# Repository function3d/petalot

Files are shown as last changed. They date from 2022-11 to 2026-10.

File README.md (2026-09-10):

# Petalot

## From PET Bottle To 3D Filament

Petalot

 - [Buy it ready-made](https://function3d.xyz/shop/)
 - [FAQs](https://function3d.xyz/faqs)
 - [How to build it](https://www.tiktok.com/@function.3d/playlist/PETALOT%20Build-7340398832935521056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)
 - [STLs](https://makerworld.com/en/models/190886-petalot-plastic-bottles-into-3d-filament)

## Bill of material
 - [BOM](https://function3d.xyz/bom/)

## Electronics

Petalot

 - [Buy it ready-made](https://function3d.xyz/shop/)
 - **UPDATE**: the firmware you need depends on your PCB version — v1.4.5 (DIY) and v1.5.1/v1.5.2 (commercial). See the [Firmware README](Firmware/README.md).
 - [Gerber](https://github.com/function3d/petalot/raw/master/Schematic/Gerber_v1.1_2023-01-02.zip) for PCB fabrication, just upload this zip file to [jlcpcb.com](https://jlcpcb.com/?from=FUNC) and order your PCB.
 - [Schematic](https://github.com/function3d/petalot/tree/master/Schematic)
 - [Firmware](https://github.com/function3d/petalot/tree/master/Firmware)
 - [Before switching on the electronics for the first time](https://github.com/function3d/petalot/blob/5b1d409dda7f66e7040381943212c45b0bf8b62b/before%20you%20switching%20on%20the%20electronics.md)
	 
## Bottle cutter
Bottle cutter

 - [Buy it ready-made](https://function3d.xyz/shop/)
 - [STLs](https://makerworld.com/en/models/190890-bottle-cutter-variable-cutting-guide-no-blades)
 - [How to build it](https://youtu.be/hEdDhRgakms)

## Social
  Follow me on [Youtube](https://www.youtube.com/channel/UC4UBuZ5YRTo5XYFUxdkmqkg), [Tiktok](https://www.tiktok.com/@function.3d) and [Instagram](https://www.instagram.com/function.3d/) for more tutorials and information.

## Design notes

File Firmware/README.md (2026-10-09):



# PETALOT Firmware

There is **one firmware**, built separately for each PCB version. The three
builds are functionally identical and share the same web UI; they only differ
in the microcontroller pin mapping (defined in `pins.hpp`). Pick the `.bin`
that matches the PCB you have installed.

## Which firmware do I need?

| PCB version | Firmware file | Availability |
| --- | --- | --- |
| **v1.4.5** | [`petalot.1.4.5-v1.6.4.bin`](petalot/build/esp8266.esp8266.d1_mini_clone/petalot.1.4.5-v1.6.4.bin) | **DIY** — the only board released publicly. |
| **v1.5.1** | [`petalot.1.5.1-v1.6.4.bin`](petalot/build/esp8266.esp8266.d1_mini_clone/petalot.1.5.1-v1.6.4.bin) | **Commercial**. |
| **v1.5.2** | [`petalot.1.5.2-v1.6.4.bin`](petalot/build/esp8266.esp8266.d1_mini_clone/petalot.1.5.2-v1.6.4.bin) | **Commercial** (current). |

- If you built your own PETALOT from the public files, your PCB is the **v1.4.5**.
- Versions **v1.5.1** and **v1.5.2** are only fitted on commercially sold machines.

> Do not flash a firmware that does not match your PCB.

## Identify your PCB

| v1.4.5 (DIY) | v1.5.1 | v1.5.2 |
| --- | --- | --- |
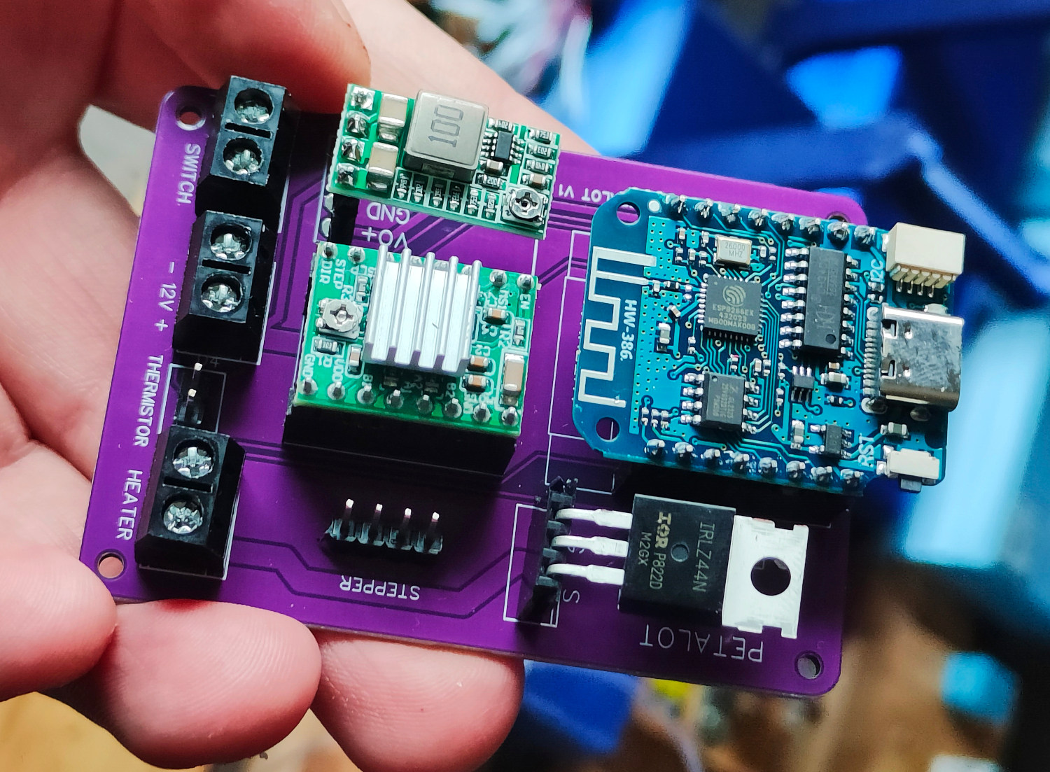
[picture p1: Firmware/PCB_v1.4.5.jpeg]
PCB v1.4.5
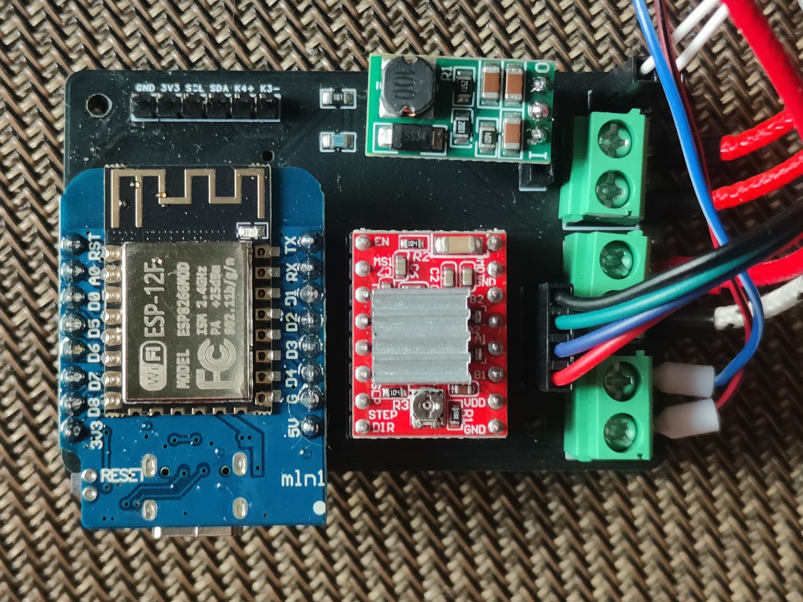
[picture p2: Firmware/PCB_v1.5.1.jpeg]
PCB v1.5.1
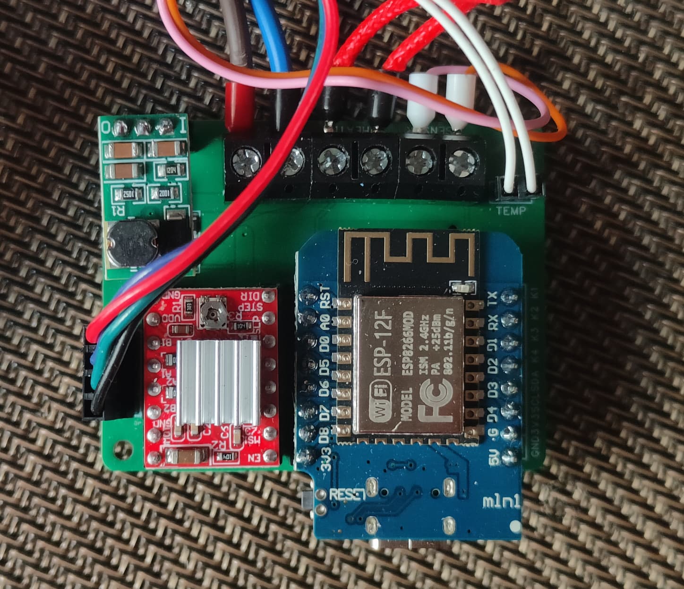
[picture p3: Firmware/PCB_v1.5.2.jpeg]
PCB v1.5.2
|  |  |  |

## First-time flash

1. Connect the Wemos to your PC.
2. Go to https://web.esphome.io/
3. Click **Connect**, select **USB Serial** port and **Connect**.
4. Click **Install**, then **Choose File**, select the `.bin` for your PCB and click **Install**.
5. Connect your phone to the Wi-Fi "PETALOT-XXXXXX" and browse to 192.168.4.1.
6. (Optional) Enter your local Wi-Fi SSID, password, IP address and subnet.

## Updating an existing device

You do not need a cable: update over the air.

### Online update (one-click, needs Internet while you do it)

Open the web UI and go to **Settings → Advanced → Online update**, then click
**Check for updates**. If a newer firmware for your PCB is available, click
**Install update** and it updates by itself.

This works when the device is connected to your home Wi-Fi: your computer or
phone is then on the same network, so it has Internet access and can fetch and
send the update. **It does not work while you are connected directly to the
device's own Wi-Fi hotspot** ("PETALOT-XXXXXX"): while connected to that, your
computer or phone has no Internet, so it cannot check or download anything. In
that case use the manual update below — it works with no Internet at all.

### Manual update (works offline, no Internet needed)

Use this if the device is not on your home Wi-Fi (for example, right out of the
box, when you connect directly to its "PETALOT-XXXXXX" network).

1. Download the `.bin` for your PCB from this repository
   (`petalot.1.4.5-v1.6.4.bin`, `petalot.1.5.1-v1.6.4.bin` or
   `petalot.1.5.2-v1.6.4.bin`).
2. Open the web UI and go to **Settings → Advanced → Firmware Update**, pick the
   file and click **Update**. (Or browse to `http://<device-ip>/update` — the
   built-in update page available on **every** firmware version.)

## Building from source

1. Open `Firmware/petalot/petalot.ino` in the Arduino IDE.
2. Set `PCB` to the hardware you are compiling for:

   | `PCB` | Hardware |
   | --- | --- |
   | `1405` | v1.4.5 |
   | `1501` | v1.5.1 |
   | `1502` | v1.5.2 |

3. Set `VERSION` to the firmware version you are publishing (e.g. `1600`).
   `VERSION` is independent of the PCB revision and is what the online update
   compares against `latest.json`.
4. Select **Tools > Board > esp8266 > LOLIN(WEMOS) D1 mini (clone)**.
5. Compile and upload.

The pin mapping for every hardware revision lives in `Firmware/petalot/pins.hpp`.
See [`INSTALL_LIBRARIES.md`](petalot/INSTALL_LIBRARIES.md) for the
required libraries and board setup.

### Previewing the web UI without flashing

[`tools/webui_preview.py`](tools/webui_preview.py) serves `web_ui.h` in your
browser (mock data, or proxied to a real device) so you can edit the UI and
press F5 — no build or flash. See [`tools/README.md`](tools/README.md).

### Publishing an online update

1. Build the three firmwares (one per `PCB`) with the new `VERSION`.
2. Regenerate the manifest:

   ```
   python3 Firmware/tools/gen_latest_json.py <VERSION>
   ```

   This writes `latest.json` next to the `.bin` files, with the version, file
   name and size for every PCB.
3. Commit and push the three `.bin` files and `latest.json` to the repository
   (the online update reads them from `master`).

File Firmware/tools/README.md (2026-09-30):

# Firmware tools

Helper scripts used to build, publish and preview the PETALOT firmware.
All are plain Python 3 / Bash with no third-party packages.

## webui_preview.py — preview the web UI without flashing

The whole UI is a single C raw string inside `petalot/web_ui.h`. This script
extracts it and serves it over HTTP, answering the device API (`/get`, `/tele`,
`/set`, `/reset`, `/updatecheck`, `/update`) so you can open the UI in a
browser and iterate on it. `web_ui.h` is re-read on every page request, so
editing it and pressing **F5** is enough — no build, no flash.

```bash
Firmware/tools/webui_preview.py                        # mock, http://0.0.0.0:8080
Firmware/tools/webui_preview.py --device http://192.168.4.1   # proxy to a device
Firmware/tools/webui_preview.py --port 9000 --open
```

Two modes:

- **Mock** (default): answers the API with synthetic data (a slowly warming
  temperature, moving counters, editable settings). Good for layout, i18n and
  styling work with no hardware at all.
- **Proxy** (`--device URL`): serves the local HTML but forwards the API to a
  real device, so you preview your UI changes against live data. Use the device
  AP address (`http://192.168.4.1`) or its LAN IP.

Options:

| Option | Meaning |
| --- | --- |
| `--host` | bind address (default `0.0.0.0`, reachable from your phone) |
| `--port` | port (default `8080`) |
| `--device URL` | proxy the device API to this URL instead of mock data |
| `--open` | open the preview in the default browser |

Note: the online update check downloads `latest.json` and the `.bin` from
GitHub **in your browser**, so that part works in the preview too.

## check_web_ui.py — static UI checks

The UI lives in one big string; a stray apostrophe or unbalanced brace breaks
it silently. This checker catches that plus i18n key mismatches. `release.sh`
runs it before every build.

```bash
python3 Firmware/tools/check_web_ui.py [Firmware/petalot/web_ui.h]
```

The checker also warns when `web_ui_gz.h` is older than `web_ui.h` (i.e. the
gzip-packed UI on device is stale).

## gen_web_gzip.py — pack the UI into a gzip PROGMEM blob

The web UI is ~100 KB of HTML/CSS/JS. Serving it compressed makes page loads
much faster on the ESP's slow WiFi. This script gzip-compresses the `INDEX_HTML`
raw string from `web_ui.h` and writes `web_ui_gz.h` (bytes + length + ETag),
which `server.hpp` serves with `Content-Encoding: gzip`.

```bash
python3 Firmware/tools/gen_web_gzip.py          # web_ui.h -> web_ui_gz.h
python3 Firmware/tools/gen_web_gzip.py --input path/web_ui.h --output path/web_ui_gz.h
```

Run it after **every** edit to `web_ui.h`, or `release.sh` will do it for you.
The gzip is deterministic (mtime=0) so the ETag is stable across identical
inputs.

## gen_latest_json.py — regenerate the update manifest

Writes `latest.json` (the file the browser reads for the online update) with
the version, file name and size of each PCB build.

```bash
python3 Firmware/tools/gen_latest_json.py <VERSION>
```

## release.sh — build and publish a release

Builds the three PCB flavours (1405 / 1501 / 1502), writes the versioned
binaries `petalot.<hw>-v<fw>.bin`, deletes the previous versioned builds,
regenerates `latest.json` and updates the file names in `Firmware/README.md`.

```bash
Firmware/tools/release.sh          # build with the VERSION already in petalot.ino
Firmware/tools/release.sh 1601     # set VERSION 1601 (= 1.6.1) and build

git add Firmware/petalot/petalot.ino Firmware/petalot/build/esp8266.esp8266.d1_mini_clone/ Firmware/README.md
git commit -m "firmware: v1.6.1"
git push
```

Environment overrides: `ARDUINO_CLI`, `ARDUINO_CLI_CONFIG`, `FQBN`.

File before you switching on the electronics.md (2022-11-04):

# Before switching on the electronics for the first time
## Set to 5V output on D3 DC-DC step down
### Option 1
- You put 12v between IN and GND
- With a multimeter you measure VO and GND
- Turn the potentiometer until you measure 5V
### Option 2
- Cut the jumper on ADJ
- Put a drop of tin on the 5V jumper

# Adjust the reference voltage of the stepper drive
You have to adjust it to supply 1A to the motor, this way the motor will hardly heat up and it will have enough power.
- Turn off the electronics
- Disconnect the motor
- Turn on the electronics
- Stop from the web interface so that the hotend is not heating up
- Measure the voltage between the small potentiometer on the driver and ground
- Turn the potentiometer until you measure is about 0.4V (0.4*2.5=1A)
- Once adjusted, turn off the electronics
- Connect the motor
- Turn on the electronics again

Never connect/disconnect the motor with the electronic on

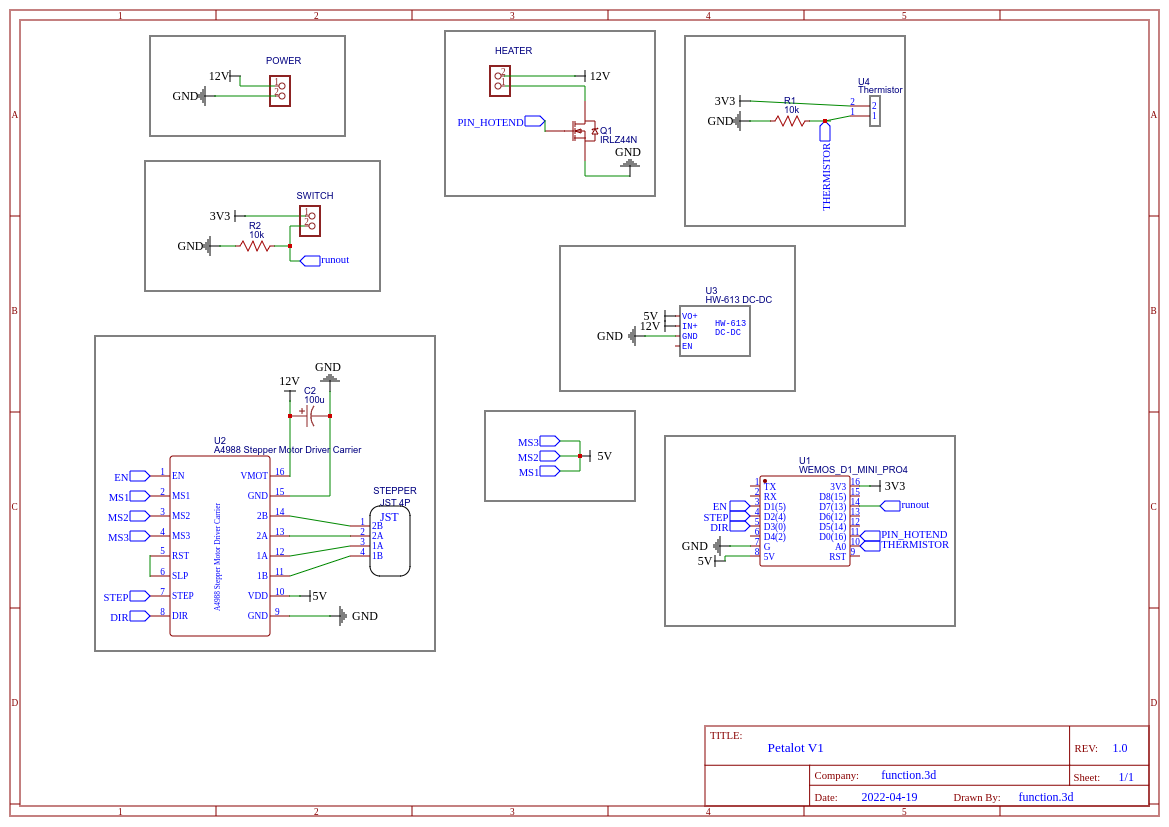
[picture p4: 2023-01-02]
Schematic/Schematic_petalot_2022-12-18.png

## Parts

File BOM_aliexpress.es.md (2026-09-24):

Precios actualizados: **25/09/2026**. Valores orientativos, pueden variar con el tiempo — consulta el precio actual en AliExpress.

## Totales

| Lista | Total |
|---|---|
| Máquina PETALOT | 39,02 € |
| Electrónica para PETALOT | 56,47 € |
| Cortador de botellas | 20,58 € |
| Herramientas | 42,98 € |
| **TOTAL (mínimo, sin envío)** | **159,05 €** |

## Máquina PETALOT

| Cant. | Componente | Enlace | Precio |
|---|---|---|---|
| 18 | Tornillo M2.3 x 20mm (unión entre el engranaje grande y la polea) | https://s.click.aliexpress.com/e/_c3eyUDcN | 1,75 € |
| 2 | Tornillo M2 x 12mm (fija la PCB a la base de madera) | https://s.click.aliexpress.com/e/_c3eyUDcN | 1,28 € |
| 3 | Tornillo M4 x 35mm (bloque central de madera y escuadra) | https://s.click.aliexpress.com/e/_onWNJ8P | 2,94 € |
| 14 | Tornillo M3 x 20mm (para atornillar las distintas partes a la base de madera) | https://s.click.aliexpress.com/e/_onWNJ8P | 2,04 € |
| 1 | Boquilla V6 de acero inoxidable 0.4 mm | https://s.click.aliexpress.com/e/_c3ejwXiT | 0,26 € |
| 4 | Rodamiento 8x22x7 mm 608RS | https://s.click.aliexpress.com/e/_DFmmUC5 | 3,69 € |
| 1 | Escuadra en ángulo de 90 grados 20x20mm | https://s.click.aliexpress.com/e/_c4VSPnbL | 2,69 € |
| 2 | M8x110mm varilla roscada (yo uso varilla roscada cortada a 10,5 cm) | https://s.click.aliexpress.com/e/_DeTWIUt | 6,78 € |
| 4 | Tuerca autoblocante hexagonal M8 con inserción de nailon | https://s.click.aliexpress.com/e/_c31WJI0D | 3,39 € |
| 3 | Tornillo M3 8mm para el engranaje del motor, caja electrónica y soporte del motor | https://s.click.aliexpress.com/e/_c38WdOKJ | 1,94 € |
| 1 | Tuerca M3 para el engranaje del motor | https://s.click.aliexpress.com/e/_c4DrxHSF | 3,49 € |
| 2 | Perno M3 14mm para el soporte del motor | https://s.click.aliexpress.com/e/_c38WdOKJ | 2,54 € |
| 50cm | Hilo de nailon 1mm | https://s.click.aliexpress.com/e/_c4028B6b | 2,54 € |
| 32cm | Funda para cables 6mm | https://s.click.aliexpress.com/e/_c4qwLShV | 3,69 € |
| 1 | Base de madera para la máquina PETALOT (cortada según estas medidas) <br>Wooden base dimensions |  |  |

*No incluida en el total: la base de madera de la máquina PETALOT (cortada según las medidas de [esta imagen](https://function3d.xyz/wp-content/uploads/2026/04/cotas2.jpg)).*

## Electrónica para PETALOT

| Cant. | Componente | Enlace | Precio |
|---|---|---|---|
| 1 | PCB, gerber para fabricar la PCB; solo tienes que subir este archivo zip a jlcpcb.com y pedir tu PCB. O compra una PCB ya fabricada. | https://jlcpcb.com/?from=FUNC · https://function3d.xyz/product/pcb-for-petalot |  |
| 1 | Wemos D1 MINI V4.0 (cualquier otra versión de WeMos que comparta los pines de salida debería servir) | https://s.click.aliexpress.com/e/_DCS2eTP | 2,99 € |
| 1 | Mini DC-DC 12-24V a 5V 3A Step Down | https://s.click.aliexpress.com/e/_DDFlE5x | 4,99 € |
| 1 | Driver de motor paso a paso A4988 + disipador (es bastante fácil quemarlo, sobre todo si eres principiante; mejor 2 unidades) | https://s.click.aliexpress.com/e/_c32zgNiZ | 1,50 € |
| 1 | MOSFET IRLZ44N | https://s.click.aliexpress.com/e/_DdfBlgH | 3,09 € |
| 1 | Condensador 16V 100uf | https://s.click.aliexpress.com/e/_optaFrN | 2,27 € |
| 1 | Tira de pines macho y hembra | https://s.click.aliexpress.com/e/_DcGRnY9 | 3,79 € |
| 3 | Conector de bloque de terminales 2P | https://s.click.aliexpress.com/e/_DkqRgFn | 0,83 € |
| 1 | Resistencias de 10K ohmios R2 | https://s.click.aliexpress.com/e/_DeT9AAz | 1,70 € |
| 1 | Resistencias de 2K ohmios para R1 si la versión de firmware es >=1.4 | https://s.click.aliexpress.com/e/_DeT9AAz | 2,18 € |
| 1 | Fuente de alimentación 12v 5A | https://s.click.aliexpress.com/e/_c2zdHPX3 | 6,09 € |
| 1 | Mini micro interruptor de final de carrera con palanca de rodillo, para el sensor de tira | https://s.click.aliexpress.com/e/_c3QnPcE9 | 1,89 € |
| 1 | Motor paso a paso Nema 17, altura >=38mm, eje en forma de D (17HS4401S-Dupont) | https://s.click.aliexpress.com/e/_c39SiyRr | 11,19 € |
| 1 | Hotend MK8 12V 40W | https://s.click.aliexpress.com/e/_DnlMNy5 | 3,65 € |
| 30cm | Cable 2P 30AWG (para el sensor de tira de final de carrera, señal digital; yo uso los cables muy finos que saco de un cable de impresora LPT1 viejo) | https://s.click.aliexpress.com/e/_Dlnn1bd | 0,72 € |
| 25cm | Cable 2P 18AWG (yo uso 25 cm del cable calefactor del hotend) | https://s.click.aliexpress.com/e/_Dlnn1bd | 1,62 € |
| 1 | Toma de corriente macho 10A 250V de 3 pines IEC320 con interruptor + fusible | https://s.click.aliexpress.com/e/_DmuNpxf | 2,36 € |
| 9 | Terminales de cable crimpados con funda aislante 20AWG (alimentación de la PCB, IEC320, calefactor) | https://s.click.aliexpress.com/e/_oEJer1l | 1,06 € |
| 2 | Terminales de cable crimpados con funda aislante 24AWG (micro interruptor) | https://s.click.aliexpress.com/e/_oEJer1l | 1,06 € |
| 5 | Terminal hembra de 4.8mm | https://s.click.aliexpress.com/e/_c2xFTcyv | 0,94 € |
| 25mm | Tubo termorretráctil 5mm, para el sensor de tira y el terminal hembra de 4.8mm | https://s.click.aliexpress.com/e/_c3knUgat | 1,32 € |
| 40mm | Tubo termorretráctil 2mm, para el sensor de tira | https://s.click.aliexpress.com/e/_c3knUgat | 1,23 € |

*No incluida en el total: la PCB (se fabrica en JLCPCB).*

## Cortador de botellas

| Cant. | Componente | Enlace | Precio |
|---|---|---|---|
| 2 | Rodamientos 608 RS (prefiero RS en vez de ZZ) | https://s.click.aliexpress.com/e/_DFmmUC5 | 3,69 € |
| 5 | Tuerca hexagonal M8 | https://s.click.aliexpress.com/e/_DlmzKtL | 2,34 € |
| 3 | Arandela plana M8x16x1.5 | https://s.click.aliexpress.com/e/_Dk397ED | 1,34 € |
| 2 | Tuerca autoblocante hexagonal M8 con inserción de nailon | https://s.click.aliexpress.com/e/_c31WJI0D | 3,39 € |
| 1 | M8x50mm varilla roscada (para el rodamiento superior; yo uso varilla roscada cortada a 48mm) | https://s.click.aliexpress.com/e/_DeTWIUt | 3,29 € |
| 2 | M8x40mm varilla roscada (para el rodamiento inferior y la guía; yo uso varilla roscada cortada a 42mm y 30mm) | https://s.click.aliexpress.com/e/_DeTWIUt | 3,59 € |
| 1 | 48cm M6 varilla roscada (sirve cualquier varilla de 6mm; 48 cm es más que suficiente para botellas de 8 litros) |  |  |
| 2 | Tornillo M4 x 35mm (para fijar el cortador a una base de madera) | https://s.click.aliexpress.com/e/_onWNJ8P | 2,94 € |

*No incluida en el total: la varilla roscada 48cm M6 del cortador.*

## Herramientas

| Cant. | Componente | Enlace | Precio |
|---|---|---|---|
| 1 | Broca de 1.7mm, para la boquilla Consejo: a veces es útil empezar taladrando con una broca más pequeña (1,5 mm) y terminar con la de 1,7 mm para evitar que el agujero se agrande hasta 2 mm | https://s.click.aliexpress.com/e/_c2xYqLsv | 2,03 € |
| 1 | Juego de brocas para azulejo, vidrio, hormigón y cerámica, 8mm, 6mm, para el bloque calefactor | https://s.click.aliexpress.com/e/_c3XyeMwN | 5,69 € |
| 1 | Soldador eléctrico de 80W con pantalla LCD digital y temperatura ajustable | https://s.click.aliexpress.com/e/_opQlTJh | 11,19 € |
| 1 | Hilo de estaño para soldar 1mm | https://s.click.aliexpress.com/e/_c44dnlgz | 5,59 € |
| 1 | Alicate crimpador, cortacables y pelacables para terminales | https://s.click.aliexpress.com/e/_oodj3Yb | 9,19 € |
| 1 | Alicate de crimpar para terminales tubulares y fundas | https://s.click.aliexpress.com/e/_oEekGpt | 9,29 € |

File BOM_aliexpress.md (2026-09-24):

Prices updated: **2026-09-25**. Indicative values, they may vary over time — check AliExpress for the current price.

## Totals

| List | Total |
|---|---|
| PETALOT machine | 39.02 € |
| Electronics for PETALOT | 56.47 € |
| Bottle Cutter | 20.58 € |
| Tools | 42.98 € |
| **TOTAL (minimum, no shipping)** | **159.05 €** |

## PETALOT machine

| Qty | Component | Link | Price |
|---|---|---|---|
| 18 | Screw M2.3 x 20mm (union between Large Gear and Pulley) | https://s.click.aliexpress.com/e/_c3eyUDcN | 1.75 € |
| 2 | Screw M2 x 12mm (fix PCB to wood base) | https://s.click.aliexpress.com/e/_c3eyUDcN | 1.28 € |
| 3 | Screw M4 x 35mm (central wooden block and Angle Bracket) | https://s.click.aliexpress.com/e/_onWNJ8P | 2.94 € |
| 14 | Screw M3 x 20mm (to screw the different parts to the wood base) | https://s.click.aliexpress.com/e/_onWNJ8P | 2.04 € |
| 1 | V6 Stainless steel nozzle 0.4 mm | https://s.click.aliexpress.com/e/_c3ejwXiT | 0.26 € |
| 4 | Bearing 8x22x7 mm 608RS | https://s.click.aliexpress.com/e/_DFmmUC5 | 3.69 € |
| 1 | 90 Degree Angle Bracket 20x20mm | https://s.click.aliexpress.com/e/_c4VSPnbL | 2.69 € |
| 2 | M8x110mm Threaded Rod (I use rod thereaded cut to 10.5cm) | https://s.click.aliexpress.com/e/_DeTWIUt | 6.78 € |
| 4 | M8 Hex Nylon Insert Lock Nut Self-locking Locknut | https://s.click.aliexpress.com/e/_c31WJI0D | 3.39 € |
| 3 | Screw M3 8mm for the motor gear, electronic box and motor mount | https://s.click.aliexpress.com/e/_c38WdOKJ | 1.94 € |
| 1 | M3 nut for the motor gear | https://s.click.aliexpress.com/e/_c4DrxHSF | 3.49 € |
| 2 | M3 14mm bolt for motor mount | https://s.click.aliexpress.com/e/_c38WdOKJ | 2.54 € |
| 50cm | Nylon thread 1mm | https://s.click.aliexpress.com/e/_c4028B6b | 2.54 € |
| 32cm | Cable Sleeve 6mm | https://s.click.aliexpress.com/e/_c4qwLShV | 3.69 € |
| 1 | Wooden base for the PETALOT machine (cut to these dimensions) <br>Wooden base dimensions |  |  |

*Not included in the total: the wooden base for the PETALOT machine (cut to the dimensions in [this image](https://function3d.xyz/wp-content/uploads/2026/04/cotas2.jpg)).*

## Electronics for PETALOT

| Qty | Component | Link | Price |
|---|---|---|---|
| 1 | PCB, gerber for PCB fabrication, just upload this zip file to jlcpcb.com and order your PCB. Or buy a ready-made PCB. | https://jlcpcb.com/?from=FUNC · https://function3d.xyz/product/pcb-for-petalot |  |
| 1 | Wemos D1 MINI V4.0 (any other version of WeMos that shares the output pins should work) | https://s.click.aliexpress.com/e/_DCS2eTP | 2.99 € |
| 1 | Mini DC-DC 12-24V To 5V 3A Step Down | https://s.click.aliexpress.com/e/_DDFlE5x | 4.99 € |
| 1 | A4988 stepper motor driver+heat sink (It is quite easy to burn it, especially if you are a beginner, better 2 units) | https://s.click.aliexpress.com/e/_c32zgNiZ | 1.50 € |
| 1 | IRLZ44N MOSFET | https://s.click.aliexpress.com/e/_DdfBlgH | 3.09 € |
| 1 | capacitor 16V 100uf | https://s.click.aliexpress.com/e/_optaFrN | 2.27 € |
| 1 | pin header Male and Female | https://s.click.aliexpress.com/e/_DcGRnY9 | 3.79 € |
| 3 | Terminal Block Connector 2P | https://s.click.aliexpress.com/e/_DkqRgFn | 0.83 € |
| 1 | 10K ohms resistors R2 | https://s.click.aliexpress.com/e/_DeT9AAz | 1.70 € |
| 1 | 2K ohms resistors for R1 if firmware version >=1.4 | https://s.click.aliexpress.com/e/_DeT9AAz | 2.18 € |
| 1 | Power Supply 12v 5A | https://s.click.aliexpress.com/e/_c2zdHPX3 | 6.09 € |
| 1 | Mini Micro Limit Switch Roller Lever Arm, for strip sensor | https://s.click.aliexpress.com/e/_c3QnPcE9 | 1.89 € |
| 1 | Nema 17 stepper motor height >=38mm D shaped shaft (17HS4401S-Dupont) | https://s.click.aliexpress.com/e/_c39SiyRr | 11.19 € |
| 1 | Hotend MK8 12V 40W | https://s.click.aliexpress.com/e/_DnlMNy5 | 3.65 € |
| 30cm | Wire 2P 30AWG (for limit switch strip sensor, digital signal, I use the very thin wires stripped from an old LPT1 printer cable) | https://s.click.aliexpress.com/e/_Dlnn1bd | 0.72 € |
| 25cm | Wire 2P 18AWG (I use 25cm from the hotend heater cable) | https://s.click.aliexpress.com/e/_Dlnn1bd | 1.62 € |
| 1 | 10A 250V Male Power Socket 3 Pin IEC320 switch + Fuse | https://s.click.aliexpress.com/e/_DmuNpxf | 2.36 € |
| 9 | Terminal Wire Conector Crimp Insulated Ferrule 20AWG (PCB power, IEC320, heater) | https://s.click.aliexpress.com/e/_oEJer1l | 1.06 € |
| 2 | Terminal Wire Conector Crimp Insulated Ferrule 24AWG (micro switch) | https://s.click.aliexpress.com/e/_oEJer1l | 1.06 € |
| 5 | 4.8mm Female Terminal | https://s.click.aliexpress.com/e/_c2xFTcyv | 0.94 € |
| 25mm | Heat Shrink Tube 5mm, for strip sensor and 4.8mm Female Terminal | https://s.click.aliexpress.com/e/_c3knUgat | 1.32 € |
| 40mm | Heat Shrink Tube 2mm, for strip sensor | https://s.click.aliexpress.com/e/_c3knUgat | 1.23 € |

*Not included in the total: the PCB (fabricated at JLCPCB).*

## Bottle Cutter

| Qty | Component | Link | Price |
|---|---|---|---|
| 2 | 608 RS bearings (I prefer RS instead of ZZ) | https://s.click.aliexpress.com/e/_DFmmUC5 | 3.69 € |
| 5 | Hex Nut M8 | https://s.click.aliexpress.com/e/_DlmzKtL | 2.34 € |
| 3 | Flat Washer M8x16x1.5 | https://s.click.aliexpress.com/e/_Dk397ED | 1.34 € |
| 2 | M8 Hex Nylon Insert Lock Nut Self-locking Locknut | https://s.click.aliexpress.com/e/_c31WJI0D | 3.39 € |
| 1 | M8x50mm Threaded Rod (for high bearing, I use rod thereaded cut to 48mm) | https://s.click.aliexpress.com/e/_DeTWIUt | 3.29 € |
| 2 | M8x40mm Threaded Rod (for low bearing and guide, I use rod thereaded cut to 42mm and 30mm) | https://s.click.aliexpress.com/e/_DeTWIUt | 3.59 € |
| 1 | 48cm M6 Threaded Rod (any 6mm rod will do, 48 cm is more than enough for 8-liter bottles) |  |  |
| 2 | Screw M4 x 35mm (to fix the cutter to a wooden base) | https://s.click.aliexpress.com/e/_onWNJ8P | 2.94 € |

*Not included in the total: the 48cm M6 threaded rod for the Bottle Cutter.*

## Tools

| Qty | Component | Link | Price |
|---|---|---|---|
| 1 | 1.7mm drill bit, for the nozzle Tip: It’s sometimes helpful to start by drilling with a smaller bit (1.5 mm) and then finish with the 1.7 mm bit to prevent the hole from expanding to 2 mm | https://s.click.aliexpress.com/e/_c2xYqLsv | 2.03 € |
| 1 | Tile Drill Bits Set for Glass Concrete Ceramic, 8mm, 6mm, for heater block | https://s.click.aliexpress.com/e/_c3XyeMwN | 5.69 € |
| 1 | 80W Electric Soldering Iron LCD Digital display Temperature Adjustable | https://s.click.aliexpress.com/e/_opQlTJh | 11.19 € |
| 1 | Solder Wire Tin 1mm | https://s.click.aliexpress.com/e/_c44dnlgz | 5.59 € |
| 1 | Crimper Cable Cutter Wire Stripper Stripping Crimping Pliers Terminal | https://s.click.aliexpress.com/e/_oodj3Yb | 9.19 € |
| 1 | Crimping Pliers Ferrule Sleeves Tubular Terminal | https://s.click.aliexpress.com/e/_oEekGpt | 9.29 € |

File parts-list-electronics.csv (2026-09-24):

qty | image_url | description | aliexpress_link | variation | price | lot | status
1 | https://function3d.xyz/wp-content/uploads/2025/08/14614565_1_top_purple_small-300x214.png | PCB, <a href="https://github.com/function3d/petalot/raw/master/Schematic/Gerber_v1.1_2023-01-02.zip">gerber</a> for PCB fabrication, just upload this <a href="https://github.com/function3d/petalot/raw/master/Schematic/Gerber_v1.1_2023-01-02.zip">zip</a> file to <a href="https://jlcpcb.com/?from=FUNC">jlcpcb.com</a> and order your PCB. Or <a href="https://function3d.xyz/product/pcb-for-petalot">buy a ready-made PCB</a>. |  |  |  |  | pcb
1 | https://function3d.xyz/wp-content/uploads/2025/07/wemos-300x278.webp | Wemos <strong>D1 MINI</strong> V4.0 (any other version of WeMos that shares the output pins should work) | https://s.click.aliexpress.com/e/_DCS2eTP | D1 MINI V4.0 | 2.99 |  | ok
1 | https://function3d.xyz/wp-content/uploads/2025/07/DC-DC-300x300.webp | Mini DC-DC 12-24V To 5V 3A <strong>Step Down</strong> | https://s.click.aliexpress.com/e/_DDFlE5x |  | 4.99 | 10 | ok
1 | https://function3d.xyz/wp-content/uploads/2025/07/A4988-300x300.webp | <strong>A4988</strong> stepper motor driver+heat sink (It is quite easy to burn it, especially if you are a beginner, better 2 units) | https://s.click.aliexpress.com/e/_c32zgNiZ | A4988 | 1.5 |  | ok
1 | https://function3d.xyz/wp-content/uploads/2025/07/IRLZ44N-300x300.webp | <strong>IRLZ44N</strong> MOSFET | https://s.click.aliexpress.com/e/_DdfBlgH | IRLZ44N | 3.09 | 10 | ok
1 | https://function3d.xyz/wp-content/uploads/2025/07/condensador-300x300.webp | capacitor <strong>16V 100uf</strong> | https://s.click.aliexpress.com/e/_optaFrN | 16V100UF | 2.27 | 50 | ok
1 | https://function3d.xyz/wp-content/uploads/2025/07/pin-header-1-300x300.webp | pin header Male and Female | https://s.click.aliexpress.com/e/_DcGRnY9 |  | 3.79 | 20 | ok
3 | https://function3d.xyz/wp-content/uploads/2025/07/Terminal-Block-Connector-2P-300x300.webp | Terminal Block Connector <strong>2P</strong> | https://s.click.aliexpress.com/e/_DkqRgFn | 2P | 0.83 | 10 | ok
1 | https://function3d.xyz/wp-content/uploads/2025/07/10k-1-300x300.webp | <strong>10K</strong> ohms resistors <strong>R2</strong> | https://s.click.aliexpress.com/e/_DeT9AAz | 10K | 1.7 | 100 | ok
1 | https://function3d.xyz/wp-content/uploads/2025/07/2k-300x300.webp | <strong>2K</strong> ohms resistors <strong>for R1 if firmware version >=1.4</strong> | https://s.click.aliexpress.com/e/_DeT9AAz | 2K | 2.18 | 100 | ok
1 | https://function3d.xyz/wp-content/uploads/2025/07/Power-Supply-300x300.webp | Power Supply <strong>12v 5A</strong> | https://s.click.aliexpress.com/e/_c2zdHPX3 |  | 6.09 |  | ok
1 | https://function3d.xyz/wp-content/uploads/2025/07/Micro-Limit-Switch-Roller-Lever-Arm-300x300.webp | Mini Micro Limit Switch <strong>Roller Lever Arm</strong>, for strip sensor | https://s.click.aliexpress.com/e/_c3QnPcE9 | Pulley | 1.89 | 10 | ok
1 | https://function3d.xyz/wp-content/uploads/2025/07/nema17-300x300.webp | <strong>Nema 17</strong> stepper motor <strong>height >=38mm</strong> D shaped shaft (<strong>17HS4401S-Dupont)</strong> | https://s.click.aliexpress.com/e/_c39SiyRr |  | 11.19 |  | ok
1 | https://function3d.xyz/wp-content/uploads/2025/07/hotend-1-300x300.webp | Hotend MK8 <strong>12V 40W</strong><a rel="fancybox" href="https://function3d.xyz/wp-content/uploads/2026/05/heater-block-3.webp"><img rel="lightbox" width="160" src="https://function3d.xyz/wp-content/uploads/2026/05/heater-block-3.webp" /></a> | https://s.click.aliexpress.com/e/_DnlMNy5 |  | 3.65 |  | ok
30cm | https://function3d.xyz/wp-content/uploads/2025/07/wire.webp | Wire <strong>2P</strong> <strong>30AWG</strong> (for limit switch strip sensor, digital signal, I use the very thin wires stripped from an old LPT1 printer cable) | https://s.click.aliexpress.com/e/_Dlnn1bd | 30AWG | 0.72 | 1 | ok
25cm | https://function3d.xyz/wp-content/uploads/2025/07/wire.webp | Wire <strong>2P 18AWG</strong> (I use 25cm from the hotend heater cable) | https://s.click.aliexpress.com/e/_Dlnn1bd | 18AWG | 1.62 | 1 | ok
1 | https://function3d.xyz/wp-content/uploads/2025/07/IEC320-300x300.webp | 10A 250V Male Power Socket 3 Pin IEC320 <strong>switch + Fuse</strong> | https://s.click.aliexpress.com/e/_DmuNpxf |  | 2.36 |  | ok
9 | https://function3d.xyz/wp-content/uploads/2025/07/terminals-1.webp | Terminal Wire Conector Crimp Insulated Ferrule <strong>20AWG</strong> (PCB power, IEC320, heater) | https://s.click.aliexpress.com/e/_oEJer1l | 20AWG | 1.06 | 100 | ok
2 | https://function3d.xyz/wp-content/uploads/2025/07/terminals-1.webp | Terminal Wire Conector Crimp Insulated Ferrule <strong>24AWG</strong> (micro switch) | https://s.click.aliexpress.com/e/_oEJer1l | 24AWG | 1.06 | 100 | ok
5 | https://function3d.xyz/wp-content/uploads/2026/09/4.8mm-female-terminal.webp | <strong>4.8mm Female Terminal</strong> | https://s.click.aliexpress.com/e/_c2xFTcyv | 4.8mm Female | 0.94 | 50 | ok
25mm | https://function3d.xyz/wp-content/uploads/2026/03/tube.jpg | <strong>Heat Shrink Tube 5mm, for strip sensor and 4.8mm Female Terminal</strong> | https://s.click.aliexpress.com/e/_c3knUgat | 5mm | 1.32 | 1 | ok
40mm | https://function3d.xyz/wp-content/uploads/2026/03/tube.jpg | <strong>Heat Shrink Tube 2mm, for strip sensor</strong> | https://s.click.aliexpress.com/e/_c3knUgat | 2mm | 1.23 | 1 | ok

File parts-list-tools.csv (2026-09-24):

qty | image_url | description | aliexpress_link | variation | price | lot | status
1 | https://function3d.xyz/wp-content/uploads/2025/07/1.7mm-drill-bit.webp | <strong>1.7mm</strong> drill bit, <strong>for the nozzle</strong><br><small>Tip: It’s sometimes helpful to start by drilling with a smaller bit (1.5 mm) and then finish with the 1.7 mm bit to prevent the hole from expanding to 2 mm</small> | https://s.click.aliexpress.com/e/_c2xYqLsv | 1.7mm | 2.03 | 10 | ok
1 | https://function3d.xyz/wp-content/uploads/2025/07/Drill-Bits-Set-for-Glass-161x300.webp | Tile Drill Bits Set for Glass Concrete Ceramic, <strong>8mm, 6mm, for heater block</strong><a rel="fancybox" href="https://function3d.xyz/wp-content/uploads/2026/05/heater-block-3.webp"><img align="right" rel="lightbox" width="160" src="https://function3d.xyz/wp-content/uploads/2026/05/heater-block-3.webp" /></a> | https://s.click.aliexpress.com/e/_c3XyeMwN | 6x8x10x12mm | 5.69 |  | ok
1 | https://function3d.xyz/wp-content/uploads/2025/07/iron-300x273.webp | 80W Electric Soldering Iron LCD Digital display Temperature Adjustable | https://s.click.aliexpress.com/e/_opQlTJh | 80W 220V | 11.19 |  | ok
1 | https://function3d.xyz/wp-content/uploads/2025/08/tin-284x300.webp | Solder Wire Tin <strong>1mm</strong> | https://s.click.aliexpress.com/e/_c44dnlgz | 1,0 mm | 5.59 |  | ok
1 | https://function3d.xyz/wp-content/uploads/2025/07/Crimper-140x300.webp | Crimper Cable Cutter Wire Stripper Stripping Crimping Pliers Terminal | https://s.click.aliexpress.com/e/_oodj3Yb |  | 9.19 |  | ok
1 | https://function3d.xyz/wp-content/uploads/2025/07/Crimping2-159x300.webp | Crimping Pliers Ferrule Sleeves Tubular Terminal | https://s.click.aliexpress.com/e/_oEekGpt |  | 9.29 |  | ok

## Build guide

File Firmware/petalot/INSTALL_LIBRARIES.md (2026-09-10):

# Installing the Libraries to Compile the PETALOT Firmware

This guide explains how to set up the Arduino IDE so you can compile this
firmware for the **LOLIN (WEMOS) D1 mini**.

## 1. Add the ESP8266 board support

1. Open the Arduino IDE.
2. Go to **File > Preferences** (labeled **File > Settings** in some versions).
3. In the **Additional Boards Manager URLs** field, paste:

   ```
   https://arduino.esp8266.com/stable/package_esp8266com_index.json
   ```

4. Click **OK** to save your preferences.
5. Go to **Tools > Board > Boards Manager**.
6. Type `esp8266` in the search box, locate **esp8266 by ESP8266 Community** and click **Install**.
7. Select the board: **Tools > Board > esp8266 > LOLIN(WEMOS) D1 mini (clone)**.

## 2. Install the required libraries

Go to **Sketch > Include Library > Manage Libraries...** and install each of the
following using the exact names shown. The Libraries Manager filter must be set
to **All** (or **Updatable** if you are reinstalling).

| Library | Purpose |
| --- | --- |
| ArduinoJson | Configuration files (`.json`) |
| AccelStepper | Stepper motor control |
| Adafruit SSD1306 | OLED display support (optional hardware) |
| ESPAsyncTCP | Networking layer required by ESPAsyncWebServer |
| ESPAsyncWebServer | Embedded web server |
| ESPAsyncHTTPUpdateServer (2.0.0) | Over-the-air (OTA) firmware updates |

> **Note:** `ESPAsyncTCP` is a dependency of `ESPAsyncWebServer`; install it
> first. `ESPAsyncHTTPUpdateServer` provides the OTA update endpoint used from
> the *Settings* page. The built-in libraries used by the firmware
> (`ArduinoOTA`, `ESP8266WiFi`, `ESP8266mDNS`, `LittleFS`, `Wire`) are included
> with the ESP8266 board package installed in step 1, so you do not need to
> install them separately.

After the libraries are installed, restart the Arduino IDE and reopen the
project before compiling.

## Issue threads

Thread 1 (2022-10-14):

In the drawings some measures are missing a decimal separator

The-Force, 2022-10-14:
Not a big deal but In the drawings some measures are missing a decimal separator:
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

function3d, 2022-10-14:
Thanks for the warning, I will correct it soon

El vie, 14 oct 2022 14:26, The-Force ***@***.***> escribió:

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

function3d, 2022-10-27:
drawing fixed

Closed 2022-10-27.

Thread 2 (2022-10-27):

Always false condition in hotend.hpp

javiersanzsanchez, 2022-10-27:
On strat method the condition "if (tempLastStart == 0)" will never be true do to "tempLastStart = millis();" on previous line.

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

function3d, 2022-10-27:
In the "stop" method there is a "tempLastStart=0" so after a manual or end filament "Stop" event, "if (tempLastStart == 0)" will be true

javiersanzsanchez, 2022-10-27:
I think no... you set "tempLastStart = millis();" so it will never be zero after that.

function3d, 2022-10-27:
the code of the start method is only executed the first time it is called after a stop, the following times it is called it is not executed because of that condition

function3d, 2022-10-27:
anyway, what issue is this condition causing you?

javiersanzsanchez, 2022-12-05:
No, is not completed

function3d, 2022-12-06:
I'm not going to recode something that works no matter how amateurish you think it is

Closed 2022-12-05.

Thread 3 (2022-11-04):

Probleme pcb

Stevoidex, 2022-11-04:
Bonjour je trouve Fantastique votre travail j ai voulu reproduire ce que vous avais fait tout fonctionne jusqu au moment de toute allumer la carte D1 ce mes a bruler sur le composant u3 je les refait 2 fois et j en ai bruler 2 j'utilise une alimentation 12v 5a si vous pouvez m aider ça serai sympa

Stevoidex, 2022-11-04:
![Uploading 20221104_195440.jpg…]()

Stevoidex, 2022-11-04:
![Uploading 20221104_195440.jpg…]()

Stevoidex, 2022-11-04:
![Uploading 20221104_195400.jpg…]()

Stevoidex, 2022-11-04:
https://zupimages.net/up/22/44/nou6.jpg

Stevoidex, 2022-11-04:
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

Stevoidex, 2022-11-04:
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

function3d, 2022-11-04:
Did you set the U3(HW-613) to 5 volts with the potentiometer?
Avez-vous réglé le U3(HW-613) sur 5 volts avec le potentiomètre?

Stevoidex, 2022-11-04:
Merci pour votre réponse, Non  c'est ce que j ai vue en cherchent mes je ne connais pas du tout  que faut t il souder ? Le 12v et le 2. 5v ? Faut t il donner un coup de couteau dans la ligne noir ? Comment fonctionne le potentiomètre

function3d, 2022-11-04:
You put 12v between IN and GND, and with a multimeter you measure VO and
GND, turn the potentiometer until you measure 5V, another option is to cut
the jumper on ADJ and put a drop of tin on the 5V jumper

El vie, 4 nov 2022, 21:50, Stevoidex ***@***.***> escribió:

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

function3d, 2022-11-05:
Vous mettez 12v entre IN et GND, et avec un multimètre vous mesurez VO et
GND, tournez le potentiomètre jusqu'à ce que vous mesuriez 5V, une autre option consiste à couper
couper le cavalier sur ADJ et mettre une goutte d'étain sur le cavalier 5V.

Stevoidex, 2022-11-05:
Merci beaucoup j ai tournez le potentiomètre sur 5v comme vous l avais expliqué c est nickel  la buse chauffe le détecteur filaments fonctionne mes le moteur ne tourne pas je les tester il fonctionne mes y a t il quelque chose a tourné sur le la carte moteur pas à pas ou a t elle pu griller comment la tester

function3d, 2022-11-05:
The stepper motor driver has only one valid position assuming you have it properly plugged in, if it does not work it is probably broken, the only way to know if it is broken is to try another driver

function3d, 2022-11-05:
Never connect/disconnect the motor with the electronic on

https://github.com/function3d/petalot/blob/master/before%20you%20switching%20on%20the%20electronics.md

Stevoidex, 2022-11-05:
J ai meusurer et il meusure bien 0,4 v le moteur ne tourne pas je vais donc voir pour en racheter une merci encore pour votre aide

Stevoidex, 2022-11-14:
Bonjour j en ai racheter un nouveau tout fonctionne mes le problème maintenant est le moteur ne tourne pas vraiment il vibre

https://user-images.githubusercontent.com/117478768/201705312-42afa9d7-dcf4-4057-8cb5-780f0ce6632e.mp4

function3d, 2022-11-14:
No, ignore my previous comment, I checked and the cables are interchanged on my machine as well.

function3d, 2022-11-14:
The stepper motor has two windings, the vibration can be caused by incorrect wiring and also by an unpowered or fused winding. To find out for sure you need to try with another operating stepper motor if it does the same we rule out that the engine is damaged, or connect this motor to the extruder cable of your 3d printer and spin it extruding in your printer.

Stevoidex, 2022-11-14:
Merci beaucoup pour votre aide je vien de trouver c est le moteur pas a pas qui n ai pas bien enfoncé dans les pin

Closed 2022-12-05.

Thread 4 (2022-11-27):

Schematic dimensions: board width

baschwar, 2022-11-27:
The board width states 75cm, I believe it should be 7.5cm.

function3d, 2022-12-05:
fixed

Closed 2022-12-05.

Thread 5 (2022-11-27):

BOM error, line 35

baschwar, 2022-11-27:
States M3 bolt, but links to M3 nuts

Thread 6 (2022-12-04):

Cannot connect

NickGreen98, 2022-12-04:
I cannot connect to the D1 mini to set up the wifi. I have tried multiple times. adding a way to manually enter the wifi info before flashing would be good.

function3d, 2022-12-18:
When you upload the firmware for the first time, the Wemos D1 starts a WIFI access point called PETALOT, you connect to this WIFI and navigate to the ip 192.168.1.4, here you put a free ip in your netword for the Wemos D1 as well as the parameters of your local wifi, your SSID, your WIFI password, your gateway and 255. 255.255.0 in the subnet mask, submit the form and if all goes well the Wemos D1 will connect to your WIFI and you will be able to access it through the ip you assigned in the previous step.

NickGreen98, 2022-12-18:
The WeMos D1 broadcasted the local network called petalot. None of my
devices would connect to the network to fill out the form.

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

function3d, 2023-01-02:
working on a version that works directly by loading the firmware without the need to enter wifi data and with the possibility to configure the device from the terminal via serial communication.

function3d, 2023-01-02:
The new version is uploaded, if you decide to try it, to configure the device you can use the serial monitor of arduino IDE, after uploading the firmware, open arduino IDE and its serial monitor and restart the wemos, in the serial monitor you will see a JSON with the configuration, copy and edit it complete and paste it complete, once edited, in the serial monitor input, press enter, the device will use your edited JSON input as new configuration and will restart so it will start the process of trying to connect to your WIFI if you have entered the WIFI/network data in the new configuration.

NickGreen98, 2023-01-04:
Hello,

I am still not able to connect. I am able to upload the binary using esphome-flasher, but I am still unable to upload using arduino IDE. It is missing the FS.h header file mentioned in conf.hpp, and I don't know what library that came from.

As for using the serial monitor to get the ssid and pass in, here is my output, I took out the ssid and password for safety:

`
To:Temperature
Vo:Speed
Tm:Maximum Temperature
Kp:Kp
Ki:Ki
Kd:Kd
R1:R1
Max:Maximum value for MOSFET (0-255)
ssid:SSID
password:SSID Password
LocalIP:IP address
Subnet:Subnet
Gateway:Gateway
ifttt_event_name:IFTTT Event Name
ifttt_api_key:IFTTT API Key
{"To":220,"Vo":40,"Tm":250,"Kp":23,"Ki":0.043,"Kd":160,"Max":210,"ssid":"SSID","password":"PASSWORD","LocalIP":"192.168.0.100","Subnet":"255.255.255.0","Gateway":"0.0.0.0","R1":10000,"ifttt_event_name":"","ifttt_api_key":""}
...................AP Ready
`

function3d, 2023-01-11:
Hi,

FS.h is part of the core of Arduino ESP framework, did you installed it ?
https://github.com/esp8266/Arduino

"ssid":"YourWifi","password":"YourWifiPassword","LocalIP"
:"192.168.0.100","Subnet":"255.255.255.0","Gateway":"YourIpGateway"
These parameters are from your current WIFI, with these parameters the
electronics works as a client of your WIFI network instead of as an access
point.

Regards
Raul,  function.3d

El mié, 4 ene 2023 a las 21:32, NickGreen98 ***@***.***>)
escribió:

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

Closed 2023-01-02.

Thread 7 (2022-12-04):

Arduino code does not compile

NickGreen98, 2022-12-04:
The arduino code does not compile and therefore cannot be uploaded in that fashion.

function3d, 2022-12-05:
Here is the result of my compilation with the libraries and versions that are used

`Using library ArduinoJson at version 6.19.4 in folder: /home/raul/Arduino/libraries/ArduinoJson
Using library ESP8266WiFi at version 1.0 in folder: /home/raul/.arduino15/packages/esp8266/hardware/esp8266/3.0.2/libraries/ESP8266WiFi
Using library ESP8266HTTPClient at version 1.2 in folder: /home/raul/.arduino15/packages/esp8266/hardware/esp8266/3.0.2/libraries/ESP8266HTTPClient
Using library ESP8266mDNS at version 1.2 in folder: /home/raul/.arduino15/packages/esp8266/hardware/esp8266/3.0.2/libraries/ESP8266mDNS
Using library AccelStepper at version 1.61 in folder: /home/raul/Arduino/libraries/AccelStepper
Using library Arduino-PID-Library-master at version 1.2.1 in folder: /home/raul/Arduino/libraries/Arduino-PID-Library-master
Using library ESP8266WebServer at version 1.0 in folder: /home/raul/.arduino15/packages/esp8266/hardware/esp8266/3.0.2/libraries/ESP8266WebServer
Using library ArduinoOTA at version 1.0 in folder: /home/raul/.arduino15/packages/esp8266/hardware/esp8266/3.0.2/libraries/ArduinoOTA
/home/raul/.arduino15/packages/esp8266/tools/xtensa-lx106-elf-gcc/3.0.4-gcc10.3-1757bed/bin/xtensa-lx106-elf-size -A /tmp/arduino_build_544986/petalot.ino.elf
Sketch uses 396261 bytes (37%) of program storage space. Maximum is 1044464 bytes.
Global variables use 31108 bytes (37%) of dynamic memory, leaving 50812 bytes for local variables. Maximum is 81920 bytes.`

Closed 2023-01-02.

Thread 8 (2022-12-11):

Bottle Cutter 608zz

seiler-emerson, 2022-12-11:
Sensational project, the best I've seen so far, adjusting the height of the pet was very simple, congratulations!
Do you have a version of the bottle cutter for 608zz bearings (bearings for skates and skateboards), or could you make it?
They are much cheaper and easier to find.

function3d, 2023-02-01:
https://github.com/function3d/petalot/blob/1d3898e29c7e2aea8eb5df6d3b6a3d68b28c794e/STLs/bottle%20Cutter%20608zz.stl
I will make a video with a better technique for sharpening the bearings.

Closed 2023-02-01.

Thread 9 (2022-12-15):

Heater not getting hot

ltbosox, 2022-12-15:
All set up and running except for the heater is not getting hot. How is the heater/temp controlled in the web panel? I've tried changing a couple of the values that looked like they might be the temp control, but nothing has worked.

ltbosox, 2022-12-15:
Scratch that, loose connection on the wifi module.

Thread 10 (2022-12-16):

U3 Pins swapped at Schematic

dominik2727, 2022-12-16:
Hi,

on the [schematic](https://github.com/function3d/petalot/blob/8e3ab868e7f05c3db0414e82d42e1fb3ce0f36cf/Schematic/Schematic_petalot_2022-08-18.png) at U3 DC-DC Converter the pins for GND & 12V are swapped.

function3d, 2023-01-02:
corrected

Closed 2023-01-02.

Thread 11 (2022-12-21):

BOM File is deleted from google sheets

canberkkurtulmus, 2022-12-21:
Hi,

I couldn't get the BOM sheet because it says that it is deleted. Can you provide it please?

Thanks

function3d, 2022-12-21:
From the readme.md file (English version) https://docs.google.com/spreadsheets/d/1QrsbV1TAUxwC-E0CKtm_DCh9_VTj5VazpKik1_OQ4T8/edit?usp=sharing

Sorry, the BOM link from LEEME.md (Spanish version) is broken

Closed 2023-01-02.

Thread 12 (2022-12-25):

Negative temperature value in UI

FUF1, 2022-12-25:
Thanks for making your amazing project publicly available.

I built it based on your provided schematic and used a [100k thermistor](https://3d-druckershop.com/p/thermistor-ntc-3950-100k-ohm-kaufen). Weirdly enough I get an unplausible temperature value in the UI with around -273°C (which is 0 Kelvin - so probably the measured value is unavailable for the calculation?). Of course, switching the thermistor leads does not change anything. Changing the R1 value in the settings does change the readings but not in a fruitful way. The heating stops at around 100°C (measured directly with an external probe at the nozzle).

I tried to figure out the causation of this by reading your code. But I must say, it is very advanced and I can't pin down the problem, if it is hardware or software related. I thought you or someone else here might have experience with a similar issue through your own work. Thanks in advance.

function3d, 2023-01-02:
What voltage do you supply to the thermistor?

FUF1, 2023-01-02:
Hey, thanks for your reply. I used the 3.3V noted in the schematic. After reading through different forums I found a solution that seems to work, altough I don't know if it is the standard way to do things: I put the thermistor to my 3d printer hotend to check the resistance at the target temperature and then used similar values (they were much lower, around 500-800 ohms, because the resistance drops massively with this thermistor when heated up). Then I just fired up petalot and measured the nozzle temp externally and swapped resistors until it was somewhat correct (deviation of around 3°C now). This is good enough and works. Not the problem is that the steppermotor has not enough torque to pull the filament through, but I will switch to another motor and a bigger gear train. Thanks for all your work!

function3d, 2023-01-02:
The drop in thermistor resistance is normal, this is how thermistors work, the variations in resistance is how we know what the temperature is.

The motor of my system is enough to make the filament, probably you need to cut the strip narrower, each type of bottle has its thickness and therefore its width, https://function3d.xyz/en/?Display_FAQ=267

FUF1, 2023-01-03:
Thank you for your answer. That is a good hint. I'll try to make it even smaller and experiment with it based on your list in the link.

Closed 2023-01-02.

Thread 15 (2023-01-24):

Stepper not spinning

McCakeAh, 2023-01-24:
We set up all of the components just as you had done and all worked except the stepper motor just made noise and vibrated. Any suggestions on what might be causing this? Could pins on the stepper be in the wrong order, or a bad stepper?
Thanks

function3d, 2023-01-24:
https://github.com/function3d/petalot/blob/5b1d409dda7f66e7040381943212c45b0bf8b62b/before%20you%20switching%20on%20the%20electronics.md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

El mar, 24 ene 2023, 23:22, McCakeAh ***@***.***> escribió:

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

McCakeAh, 2023-01-24:
> https://github.com/function3d/petalot/blob/5b1d409dda7f66e7040381943212c45b0bf8b62b/before%20you%20switching%20on%20the%20electronics.md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 El mar, 24 ene 2023, 23:22, McCakeAh ***@***.***> escribió:
> […](#)
> We set up all of the components just as you had done and all worked except the stepper motor just made noise and vibrated. Any suggestions on what might be causing this? Could pins on the stepper be in the wrong order, or a bad stepper? Thanks — Reply to this email directly, view it on GitHub <#15>, or unsubscribe <https://github.com/notifications/unsubscribe-auth/A2GTVH57GBI6AVMR264EFEDWUBI2PANCNFSM6AAAAAAUFUFGSQ> . You are receiving this because you are subscribed to this thread.Message ID: ***@***.***>

we have tried all that and still the same results

function3d, 2023-01-24:
Check the connector, it may be loose

El mié, 25 ene 2023, 0:38, McCakeAh ***@***.***> escribió:

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

function3d, 2023-04-04:
Check your welds, make sure you do not have two adjacent welds joined together.

Closed 2023-04-12.

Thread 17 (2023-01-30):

I would get the linked psu into the electronics box

hibobly, 2023-01-30:

function3d, 2023-01-30:
Can you explain better?

hibobly, 2023-02-01:
sorry for the spelling mistakes but the electronics is 7 cm wide and the linked psu is 7.8 cm wide

function3d, 2023-02-01:
12V 5A power supply is 58mm
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

hibobly, 2023-02-01:
thanks

Closed 2023-04-03.

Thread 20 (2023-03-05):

stepper motor driver does not show any reading when you turn the potentiometer

hibobly, 2023-03-05:
when every thing is attached the stepper motor does not move and stepper motor driver does not show a reading on the pot.
and help would be appreciated.

function3d, 2023-03-05:
Check that it is connected in the correct position and try another one

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

function3d, 2023-04-04:
Check your welds, make sure you do not have two adjacent welds joined together.

function3d, 2023-04-04:
Check your welds, make sure you do not have two adjacent welds joined together.

Closed 2023-04-03.

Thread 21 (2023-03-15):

Stepper motor doesnt work

MarmotLand, 2023-03-15:
A recently set up everything and it works but accept for stepper motor I set up the the voltage 0.4 V the stepper motor doesnt do anything any noise any spin nothing THANKS for help

gulsinho06, 2023-04-02:
Did you buy the stepper motor indicated in the video and another? if it is another one, make sure its vref and readjust the driver voltage

MarmotLand, 2023-04-02:
> Did you buy the stepper motor indicated in the video and another? if it is another one, make sure its vref and readjust the driver voltage

Im using NEMA 17 17HS3401 and i reacently came up to a conclusion that the stepper motor driver might be burnt , because I accidently disconnected the steper motor while i was testing it. And one more question whats vref ? Thanks for replying

gulsinho06, 2023-04-02:
You're welcome

function3d, 2023-04-04:
Check your welds, make sure you do not have two adjacent welds joined together

Closed 2023-04-12.

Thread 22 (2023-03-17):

Wemos D1 Mini (4mb) fried

Bullitt25, 2023-03-17:
Hi,I'm a big fan from Germany, we recently build your machine with the pcb (manufactured at JLCPCB) and all components for a school project. I set everything up and turned the potentiometers correctly, but as I turned on the whole system the wemos rustle and the led didn't get that bright anymore. I can't flash it right now because it gets very hot while writing.

I don't know if it's my fault, but I rule out a short circuit.

can I repair the wemos?

Thanks for that cool project!!!

Closed 2023-04-03.

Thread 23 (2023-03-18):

Just a little doubt

RuhtraXD, 2023-03-18:
For power do you use 2 positive and negative 12V wires connected to the board? Is there no risk of closing the circuit?

function3d, 2023-03-18:
I don't understand your question, every electrical circuit needs two wires
(positive and negative) to be powered.

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

RuhtraXD, 2023-03-18:
Should I use 12V positive and 12V negative or should I use 12V positive and negative?

function3d, 2023-03-18:
Of course, you must use 12V and ground

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

RuhtraXD, 2023-03-18:
Understood, thanks for the assistance, you're doing a great job with this project.

gulsinho06, 2024-01-03:
ruhtra meu novo dc sparkinho_ pede amizade

Closed 2023-04-01.

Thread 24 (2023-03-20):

Heatblock not heating

Biancod, 2023-03-20:
Hi, my heatblock it’s not heating, i’m not getting current on heaters pin, what should i check?

function3d, 2023-04-04:
Check your welds, make sure you do not have two welds next to each other

function3d, 2023-04-04:
Check your welds, make sure you do not have two welds next to each other

function3d, 2023-04-12:
make sure there is no weld making bad contact

Closed 2023-04-12.

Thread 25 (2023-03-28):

Stepper motor doesnt spin

Adam3359, 2023-03-28:
Hi, Function3d i have issue with my stepper motor it doesnt want to spin, I tried everything and still it doesnt want to work. What i should check ?. Thanks for respond

function3d, 2023-03-28:
1.
https://github.com/function3d/petalot/blob/5b1d409dda7f66e7040381943212c45b0bf8b62b/before%20you%20switching%20on%20the%20electronics.md

2. Check the connectors.

3. Test the motor in your 3D printer.

4. Try another stepper driver.

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

function3d, 2023-04-04:
Check your welds, make sure you do not have two adjacent welds joined together.

Closed 2023-04-12.

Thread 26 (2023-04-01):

d1 mini does not create wifi network

RuhtraXD, 2023-04-01:
I followed every step by step but the arduino does not create the wifi network called petalot.

gulsinho06, 2023-04-02:
Instale o driver do esp8266 para o chip CH340G e compile novamente

gulsinho06, 2023-04-02:
Install esp8266 driver for CH340G chip and compile again

RuhtraXD, 2023-04-02:
Where can i get this esp8266?

RuhtraXD, 2023-04-02:
Plis can you make a more detailed step by step, im thinking im doing something wrong.

gulsinho06, 2023-04-02:
Okay, the tutorial is in portuguese but you can translate https://www.robocore.net/tutoriais/instalando-driver-do-nodemcu
you must install CH340g driver

RuhtraXD, 2023-04-02:
Alright, the first tutorial i already done yesterday and it doens't work (portuguese is not a problem, im brazilian) and now i've this second tutorial, now i can flash the program on the arduino normally?

gulsinho06, 2023-04-02:
Sou br tbm posso tentalo ajudalo meu dc para contato: SPARKINHO#9289

RuhtraXD, 2023-04-02:
mostro aqui que nao da pra enviar o pedido, Ruhtra#6973 tenta o meu

Closed 2023-04-05.

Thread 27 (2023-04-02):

compilation ide

gulsinho06, 2023-04-02:
Is it possible for me to compile a new file to change the name of the wifi network and how can I put a password on it? and how do i do that i tried it in the arduino IDE and it just gave an error

Closed 2023-04-02.

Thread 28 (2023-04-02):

Which board to use in Arduino IDE?

gulsinho06, 2023-04-02:
Inside the Arduino IDE there are these boards

LOLIN(WEMOS) D1 ESP-WROOM-02
LOLIN(WEMOS) D1 R2 & mini
LOLIN(WEMOS) D1 mini (clone)
LOLIN(WEMOS) D1 mini Lite
LOLIN(WEMOS) D1 mini Pro
LOLIN(WeMos) D1 R1

Which one to use with D1 mini v3?

function3d, 2023-04-03:
LOLIN(WEMOS) D1 R2 & mini

Closed 2023-04-03.

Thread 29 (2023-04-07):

machine the hotend

gulsinho06, 2023-04-07:
What drills do you use to machine the hotend?

And is there any more didactic tutorial for me to follow?

function3d, 2023-04-07:
I use one like [this](https://media.adeo.com/marketplace/MKP/84433455/0231d78c41351987282fa4866cc16b91.jpeg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) (8mm glass drill bit) for the block and nozzle plus 1.7mm drill bit for the nozzle hole. [This](https://youtu.be/dQRuUmIxJyA) is an old video, I am planning a new video with the new drill bit

Closed 2023-04-12.

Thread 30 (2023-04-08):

What filament did you use to print the parts?

gulsinho06, 2023-04-08:
What filament did you use to print the parts?

function3d, 2023-04-08:
To date I have manufactured 8 machines, all of them with PET filament from
recycled bottles except the first one which was partially printed with PET
filament from bottles

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

gulsinho06, 2023-04-08:
how is my first machine going, would petg be the most recommended?

function3d, 2023-04-08:
Yes PETG better than PLA, but PLA should also work

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

Deses, 2023-04-14:
> To date I have manufactured 8 machines

Do you sell complete kits, by any chance?

function3d, 2023-04-15:
I am currently manufacturing on demand. Send me a email to
***@***.*** and I will send you a quote

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

Closed 2023-04-09.

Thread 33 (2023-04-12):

end of course question!

gulsinho06, 2023-04-12:
Can I use this one?

https://pt.aliexpress.com/item/1005005327520357.html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

function3d, 2023-04-12:
I don't know the dimensions of that one but if it's not the same it won't
fit.

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

gulsinho06, 2023-04-12:
Where can I find the IRLZ44N the link you provided is no longer available

function3d, 2023-04-12:
https://a.aliexpress.com/_EQTfu8r

https://a.aliexpress.com/_EuAvhxp

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

HumbleDeer, 2023-05-01:
> Where can I find the IRLZ44N the link you provided is no longer available

You can use another suitable N-channel MOSFET if you do not have this specific one on hand, as long as the pinout matches and the specifications are roughly enough for the project (eg voltage across it, and the current drawn by the heater)

Closed 2023-04-17.

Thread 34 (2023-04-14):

Length of the 6mm threaded rod.

Deses, 2023-04-14:
Hi!

In the BOM, you specify a `Threaded Rod 6mm`, but do not say the length. How long should it be?

Gracias. ;)

function3d, 2023-04-15:
A specific length is not important, it depends on how tall your bottles
are, but with 48cm most bottles would be covered.

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

Closed 2023-04-17.

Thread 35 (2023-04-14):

Dead link to AliExpress

Deses, 2023-04-14:
I've found some dead links in the BOM, and found some possibly suitable replacements. Please verify if they are the proper ones.

`Mini Micro Limit Switch Roller Lever Arm` --> https://es.aliexpress.com/item/1926553469.html
`IRLZ44N MOSFET` --> https://es.aliexpress.com/item/1005002474344551.html
`capacitor 100uf 16V` --> https://es.aliexpress.com/item/1005002842732971.html
`pin header` --> https://es.aliexpress.com/item/32735482077.html

Also, you should maybe consider migrating the BOM to a Github Wiki page to keep everything in one single resource.

Gracias!

Deses, 2023-04-14:
Here's the current table (with dead links) in markdown format in case you want to do the switch, saving you some work. :)

Code:
```
| Qty    | Name                                                                                          | Aliexpress (for reference)                 |
| ------ | --------------------------------------------------------------------------------------------- | ------------------------------------------ |
|------| Bottle cutter                                                                                 |------------------------------------------|
| 2      | bearing 6200 ZZ high speed 10x30x9                                                            | https://s.click.aliexpress.com/e/_DBCB7qJ  |
| \*2    | M8 Hex Bolt 60mm Full Thread                                                                  | https://s.click.aliexpress.com/e/_DF8rC8x  |
| \*3    | Hex Nut M8                                                                                    | https://s.click.aliexpress.com/e/_DdAzvUJ  |
| \*1    | Hexagonal Bolt Partial Thread M8 40mm DIN931                                                  | https://s.click.aliexpress.com/e/_DCCHxur  |
| \*2+   | Flat Washer M8 16x1                                                                           | https://s.click.aliexpress.com/e/_DdBx3SF  |
| \*2    | M8 Hex Nylon Insert Lock Nut Self-locking Locknut                                             | https://s.click.aliexpress.com/e/_At5Tpj   |
| \*1    | Threaded Rod 6mm (any 6mm rod will work, I used a carbon fiber rod from a kite)               | https://s.click.aliexpress.com/e/_DEQQjrz  |
|------| Electronics                                                                                   |------------------------------------------|
| 1      | Power Supply 12v 5A                                                                           | https://s.click.aliexpress.com/e/_DEF56Ef  |
| 1      | Wemos D1 MINI V3.0.0                                                                          | https://s.click.aliexpress.com/e/_9GGvad   |
| 1      | Mini DC-DC 12-24V To 5V 3A Step Down                                                          | https://s.click.aliexpress.com/e/_A8abPX   |
| 1      | Mini Micro Limit Switch Roller Lever Arm                                                      | https://s.click.aliexpress.com/e/_AqJnzx   |
| 1      | A4988 DRV8825 Stepper Motor Driver With Heat sink                                             | https://s.click.aliexpress.com/e/_AMKH4t   |
| 1      | Nema 17 stepper motor 42 motor height 38mm 1.2A D shaped shaft                                | https://s.click.aliexpress.com/e/_AfngLT   |
| 1      | IRLZ44N MOSFET                                                                                | https://s.click.aliexpress.com/e/_DkRy2Mx  |
| 1      | Hotend MK8 Extrusion Aluminum Block 20x20x10mm with Thermistor Ceramic and Heater 12V 40W     | https://s.click.aliexpress.com/e/_9QSRwl   |
| \*1    | capacitor 100uf 16V                                                                           | https://s.click.aliexpress.com/e/_DkEQAV5  |
| \*x    | pin header                                                                                    | https://s.click.aliexpress.com/e/_Ddiwa2P  |
| 3      | terminal blocks 2P                                                                            | https://s.click.aliexpress.com/e/_DdfJlAb  |
| \*2    | 10K ohms resistors                                                                            | https://s.click.aliexpress.com/e/_DkDLncf  |
| \*50cm | 2 wire cable for limit switch, digital signal                                                 | https://s.click.aliexpress.com/e/_Dlnn1bd  |
| \*50cm | 2 wire cable for 5A+                                                                          | https://s.click.aliexpress.com/e/_Dlnn1bdd |
| \*1    | 10A 250V Inlet Module Plug Rocker Switch Male Power Socket 3 Pin IEC320 C14 switch + Fuse New | https://s.click.aliexpress.com/e/_DmXiViX  |
|------| Hardware                                                                                      |------------------------------------------|
| 1      | MK8 Brass Nozzle 0.4MM                                                                        | https://s.click.aliexpress.com/e/_ANswWD   |
| 4      | Bearing 8x22x7 mm 608ZZ                                                                       | https://s.click.aliexpress.com/e/_DDu60K3  |
| 1      | Stainless Steel 90 Degree Angle Bracket Corner 20x20mm                                        | https://s.click.aliexpress.com/e/_ACOtVF   |
| \*2    | M8 x 100mm A2 Hex Head Screw Bolt                                                             | https://s.click.aliexpress.com/e/_AY2LNb   |
| \*2    | M8 Hex Nylon Insert Lock Nut Self-locking Locknut                                             | https://s.click.aliexpress.com/e/_At5Tpj   |
| \*1    | M3 8mm Bolt for the motor gear                                                                | https://s.click.aliexpress.com/e/_DelUMSF  |
| \*3    | M3 14mm Bolt for motor mount                                                                  | https://s.click.aliexpress.com/e/_DelUMSF  |
| \*50cm | Paracord 2mm(nylon string) (I used polyester thread for kite handles)                         | https://s.click.aliexpress.com/e/_99oV2Hv  |
| \*1    | 1.7mm drill bit                                                                               | https://s.click.aliexpress.com/e/_DD1SYVV  |
```
### And how it looks:
| Qty    | Name                                                                                          | Aliexpress (for reference)                 |
| ------ | --------------------------------------------------------------------------------------------- | ------------------------------------------ |
|------| Bottle cutter                                                                                 |------------------------------------------|
| 2      | bearing 6200 ZZ high speed 10x30x9                                                            | https://s.click.aliexpress.com/e/_DBCB7qJ  |
| \*2    | M8 Hex Bolt 60mm Full Thread                                                                  | https://s.click.aliexpress.com/e/_DF8rC8x  |
| \*3    | Hex Nut M8                                                                                    | https://s.click.aliexpress.com/e/_DdAzvUJ  |
| \*1    | Hexagonal Bolt Partial Thread M8 40mm DIN931                                                  | https://s.click.aliexpress.com/e/_DCCHxur  |
| \*2+   | Flat Washer M8 16x1                                                                           | https://s.click.aliexpress.com/e/_DdBx3SF  |
| \*2    | M8 Hex Nylon Insert Lock Nut Self-locking Locknut                                             | https://s.click.aliexpress.com/e/_At5Tpj   |
| \*1    | Threaded Rod 6mm (any 6mm rod will work, I used a carbon fiber rod from a kite)               | https://s.click.aliexpress.com/e/_DEQQjrz  |
|------| Electronics                                                                                   |------------------------------------------|
| 1      | Power Supply 12v 5A                                                                           | https://s.click.aliexpress.com/e/_DEF56Ef  |
| 1      | Wemos D1 MINI V3.0.0                                                                          | https://s.click.aliexpress.com/e/_9GGvad   |
| 1      | Mini DC-DC 12-24V To 5V 3A Step Down                                                          | https://s.click.aliexpress.com/e/_A8abPX   |
| 1      | Mini Micro Limit Switch Roller Lever Arm                                                      | https://s.click.aliexpress.com/e/_AqJnzx   |
| 1      | A4988 DRV8825 Stepper Motor Driver With Heat sink                                             | https://s.click.aliexpress.com/e/_AMKH4t   |
| 1      | Nema 17 stepper motor 42 motor height 38mm 1.2A D shaped shaft                                | https://s.click.aliexpress.com/e/_AfngLT   |
| 1      | IRLZ44N MOSFET                                                                                | https://s.click.aliexpress.com/e/_DkRy2Mx  |
| 1      | Hotend MK8 Extrusion Aluminum Block 20x20x10mm with Thermistor Ceramic and Heater 12V 40W     | https://s.click.aliexpress.com/e/_9QSRwl   |
| \*1    | capacitor 100uf 16V                                                                           | https://s.click.aliexpress.com/e/_DkEQAV5  |
| \*x    | pin header                                                                                    | https://s.click.aliexpress.com/e/_Ddiwa2P  |
| 3      | terminal blocks 2P                                                                            | https://s.click.aliexpress.com/e/_DdfJlAb  |
| \*2    | 10K ohms resistors                                                                            | https://s.click.aliexpress.com/e/_DkDLncf  |
| \*50cm | 2 wire cable for limit switch, digital signal                                                 | https://s.click.aliexpress.com/e/_Dlnn1bd  |
| \*50cm | 2 wire cable for 5A+                                                                          | https://s.click.aliexpress.com/e/_Dlnn1bdd |
| \*1    | 10A 250V Inlet Module Plug Rocker Switch Male Power Socket 3 Pin IEC320 C14 switch + Fuse New | https://s.click.aliexpress.com/e/_DmXiViX  |
|------| Hardware                                                                                      |------------------------------------------|
| 1      | MK8 Brass Nozzle 0.4MM                                                                        | https://s.click.aliexpress.com/e/_ANswWD   |
| 4      | Bearing 8x22x7 mm 608ZZ                                                                       | https://s.click.aliexpress.com/e/_DDu60K3  |
| 1      | Stainless Steel 90 Degree Angle Bracket Corner 20x20mm                                        | https://s.click.aliexpress.com/e/_ACOtVF   |
| \*2    | M8 x 100mm A2 Hex Head Screw Bolt                                                             | https://s.click.aliexpress.com/e/_AY2LNb   |
| \*2    | M8 Hex Nylon Insert Lock Nut Self-locking Locknut                                             | https://s.click.aliexpress.com/e/_At5Tpj   |
| \*1    | M3 8mm Bolt for the motor gear                                                                | https://s.click.aliexpress.com/e/_DelUMSF  |
| \*3    | M3 14mm Bolt for motor mount                                                                  | https://s.click.aliexpress.com/e/_DelUMSF  |
| \*50cm | Paracord 2mm(nylon string) (I used polyester thread for kite handles)                         | https://s.click.aliexpress.com/e/_99oV2Hv  |
| \*1    | 1.7mm drill bit                                                                               | https://s.click.aliexpress.com/e/_DD1SYVV  |

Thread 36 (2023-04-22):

Configs!

gulsinho06, 2023-04-22:
What do the abbreviations of the configuration that you have on the site mean

    To
    Vo
    Tm
    Kp
    Ki
    Kd
    Max
    R1
    ifttt_event_name
    ifttt_api_key

function3d, 2023-04-24:
Kp, Ki, and Kd are parameters commonly used in the PID (Proportional,
Integral, Derivative) controller. Kp is the proportional constant, Ki is
the integral constant, and Kd is the derivative constant.

R1 is the actual value of the PCB resistor R1, it is not important to be
precise with this

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

Closed 2023-04-25.

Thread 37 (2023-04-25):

Size bolts

gulsinho06, 2023-04-25:
What is the size of the screws to fix the Pulley and Large Gear and motor gear

Closed 2023-04-26.

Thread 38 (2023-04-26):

Nema 17

gulsinho06, 2023-04-26:
Is it okay if I use a nema 17 4.2 kgf? Same dimensions as the project, it can only hold more kgf

function3d, 2023-04-27:
Surely you can

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

Thorgal10, 2023-05-01:
If I connect the 12Volt then the components start to smoke

function3d, 2023-05-01:
You did something wrong before https://vm.tiktok.com/ZGJuB6V5r/

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

Thorgal10, 2023-05-01:
my connection of my capacitor begins to sizzle
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

function3d, 2023-05-01:
Link to that capacitor?

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

Thorgal10, 2023-05-01:
I think I found it, it was the leftover of the solder fluid that was causing a short circuit.

Thorgal10, 2023-05-01:
sorry,now i cant find the port for the flash

Closed 2023-05-01.

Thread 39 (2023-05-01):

Include ESPHome config file

HumbleDeer, 2023-05-01:
The ESPHome config file is required to modify the firmware. Included in the repository is only the files that ESPHome generated using the PlatformIO environment, but this is not enough to recreate the ESPHome project if any adjustments to firmware are required.

The original ESPHome config file comes in the form of a .yaml file.

HumbleDeer, 2023-05-03:
Oh, how come the use of ESPHome as a platform then?

function3d, 2023-05-03:
I don't know what ESPHome is, I just use the Arduino IDE.

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

HumbleDeer, 2023-05-03:
It's mentioned on the readme for the firmware as a requirement. 😅
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
If you use just Arduino, I will look into making some small improvements to the code to make it C++ standard compliant (proper usage of header files etc)

function3d, 2023-05-03:
Esphome-flasher is a software only for loading firmware compiled by Arduino
IDE

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

HumbleDeer, 2023-05-03:
I see.
I'll do some work on the firmware then, and plan on adding some optional
features I'd like to have. I'll do that on my fork. Cheers.

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

Closed 2023-05-09.

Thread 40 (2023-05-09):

Need of deactivating the 3g/4g connection before trying to conect to the "petalot" ssid

JesConsuegra, 2023-05-09:
@function3d Please add to the documentation the need of deactivating the 3G/4G connection in the Android phone, if not there is no connection possible. Thanks.

function3d, 2023-05-09:
The problem you report does not seem to be something absolute, I have tested it from my android phone and I have not needed to disable the 3G/4G connection.

JesConsuegra, 2023-05-09:
> I added a comment to the instructions in case the same thing happens to someone else.

Thanks a lot!

Closed 2023-05-09.

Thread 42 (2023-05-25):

No matter what i do, the heater block doesn't heat.

RuhtraXD, 2023-05-25:
i already have all the peaces of petalot, but, for some reason the heater block just dont heat. I tested all the parts that could have a bad function or problem, and everything works properlly, but when i combine everything, doesn't heat. what could be the problem?

function3d, 2023-05-28:
I can only think of a bad weld, check that there are not two adjacent welds communicating or similar

JesConsuegra, 2023-06-23:
I had the same problem. At the end it was caused by a faulty MOSFET. Ensure it is able to support the load. To test it unplug the heating element and check if there are 12 volts between the two poles of the plug in the board when you activate it from the petalot web page. If you get 12 volts , try to connect again the heating element in series with an ampmeter. If there is not enough current flowing, replace the MOSFET.

RuhtraXD, 2023-07-24:
OH i forgot to close the issue. I solve the problem a couple weeks ago and the problem was that the guy who soldered the pcb damaged the board in the mosfet GND conection and it make the heat block unable to heat, i solve using another new pcb, thank you for the support guys.

Closed 2023-07-24.

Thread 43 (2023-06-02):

Stepper motor problem

eteache, 2023-06-02:
Hi,

I've assembled everything, but the motor doesn't turn. What checks can I do?
Is it normal for the motor driver to get so hot even with the heat sink?

function3d, 2023-06-04:
Hi,  you probably have a short circuit, check the adjoining welds that are
not communicating.

El sáb, 3 jun 2023 a las 1:30, eteache ***@***.***>)
escribió:

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

scalinux, 2023-06-04:
Try testing the motor without drive using this as example. Also check youtube videos explain how to. Good luck!

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

eteache, 2023-07-14:
Motor is fine, tried to connect directly to my 3D printer and works fine. After two boards built, I think I'm welding bad some component...

Closed 2024-01-16.

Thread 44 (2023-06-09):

Arduino IDE

gulsinho06, 2023-06-09:
For which board should I compile the code? inside the esp8266 library

function3d, 2023-06-13:
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

function3d, 2023-06-13:
this is my complete list of libraries, it doesn't mean that all of them are necessary to compile the firmware, but they are all the ones that I currently have and the firmware compiles for me:

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

Closed 2023-07-22.

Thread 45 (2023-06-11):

Filament clogged

frosty884, 2023-06-11:
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

The strip is 0.25mm x 9mm.

The temperature I have changed to various points from 220-250C.  I have also tried to lower the speed.  The hotend is tested with thermometer and reads correct values.  I already have ~10cm of pulled filament, but once the strip gets to its widest point, it refuses to pull, resulting in system failure.  How can I fix this, thank you.

Closed 2023-07-05.

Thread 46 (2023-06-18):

psu beeping

onyakov, 2023-06-18:
when turning on the power psu start to beep simultaneously with led ob the motherboard. But whole system seems to be working. Can you tell what is wrong? Thanks

function3d, 2023-06-18:
What is your PSU? And what are the reasons for your PSU beeping?

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

Closed 2023-07-01.

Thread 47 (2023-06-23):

Help-me

gulsinho06, 2023-06-23:
what is the cutting width of the pet bottle? because I did all the tutorial and I can't make the filament go through the hotend

function3d, 2023-06-23:
https://function3d.xyz/en/?Display_FAQ=267

The plastic strip must be able to be pulled by hand, if you can't pull it
by hand the motor will not be able to pull it either.

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

scalinux, 2023-07-22:
You can follow this short, from the official YouTube channel.
https://youtu.be/0TZXpEN6e_o

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

Closed 2023-07-22.

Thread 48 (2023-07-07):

hotend possibly hotter than thermister reading

watsoz, 2023-07-07:
Hi, My thermister temperature is saying it's only 220C but the hotend tip is melting the PET filament and its breaking the filament strand. What could cause temperature to be hotter than thermister reading?

watsoz, 2023-07-08:
Don't worry, I figured it out- thermister was not making  good contact with heat block and giving inaccurate temp reading. Put high temp thermal grease on thermister and is working normally now

Closed 2023-07-08.

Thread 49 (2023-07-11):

ABOUT ESP8266MOD Flash

scalinux, 2023-07-11:
After flash the module it get into a loop reboot.

Re flash with original dump firmware from manufacture and get back to normal. ESP8266MOD USB-C type. 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

function3d, 2023-07-11:
This is not the module for which the firmware is compiled

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

scalinux, 2023-07-12:
Thanks.
After testing and testing keep trying the .bin file. Manage to make it work without using the flash ESPTool recommended on the firmware article.

The only change in this module is USB-C. The only way get it to flashes is via web interface ESP Web Tool, using MacBook Pro M2.

First need to flash with official ESP HOME. Second step set WIFI. Then using the https://web.esphome.io click Connect then Install the PETALOT firmware.

Make sure connect 3V on the pins. Then the USB-C to flash.

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

Then flash Official ESPHome.
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

Or web Tool.
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

Then as usual test the local ip web interface.

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

Your.bin file loaded in the Mini D1 USB-C

Thanks for sharing this project.
#scalinux

function3d, 2023-07-12:
Thank you very much for that exhaustive documentation of the case

scalinux, 2023-07-12:
Makes sure to add this to the article for GNU/Linux/MAC users.

Thanks..

function3d, 2023-07-12:
I am a Linux user and the steps I describe work well for me.

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

Closed 2023-07-13.

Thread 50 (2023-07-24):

I need to make the cutter without the 3D printed piece

RuhtraXD, 2023-07-24:
Did you have the schematic of the cutter drilling holes, so i can make it in the wood without print that piece?

function3d, 2023-07-25:
[schematic of the cutter drilling holes.pdf](https://github.com/function3d/petalot/files/12165755/schematic.of.the.cutter.drilling.holes.pdf)

Closed 2023-09-24.

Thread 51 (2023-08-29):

Motor does not change speed

kartonkafoto, 2023-08-29:
Motor does not change speed when i change it in web-interface. The speed remains 20 mm/min always. It would be great to make a slider to change the speed.

function3d, 2023-08-29:
20cm/minute is the maximum and 10cm/minute the minimum

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

kartonkafoto, 2023-08-29:
20cm/minute is so low speed. Can you make max\min values in settings for change it by user?

function3d, 2023-08-29:
The electronics cannot move the stepper motor faster, 20 is the limit, but
also and much more important the PET cannot be made faster, it needs time
to warm up.

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

Closed 2023-09-24.

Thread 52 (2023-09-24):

screws

gulsinho06, 2023-09-24:
What screw did you use to screw the pieces to the wood? and what screw did you use to screw the  spool holder to the wood?

function3d, 2023-09-24:
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

gulsinho06, 2023-09-24:
the screw that locks the motor gear Can I use an m3x8 allen screw?

Closed 2023-09-24.

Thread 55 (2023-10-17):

WIFI SECURITY

gulsinho06, 2023-10-17:
where do I set the wifi password?

function3d, 2023-10-17:
There is no password for the PETALOT-XXXXXX wifi, you can connect to your
home wifi as a client from the settings so the PETALOT-XXXXXX wifi will no
longer exist.

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

gulsinho06, 2023-10-17:
I wanted to put a password, how do I do it?

function3d, 2023-10-17:
You will have to program the code and compile new firmware

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

Closed 2024-01-16.

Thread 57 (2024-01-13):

Demande de fichier

NvidiaZfr, 2024-01-13:
Pourquoi n'existe-t-il pas de centre de poulie ?

function3d, 2024-01-16:
Il n'est plus nécessaire, il est inclus dans "large gear x2.stl".

> Message ID: ***@***.***>
>

NvidiaZfr, 2024-01-16:
d'accord merci

Closed 2024-01-16.

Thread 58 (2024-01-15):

cuscinetti a sfera

WillianGallina, 2024-01-15:
qualche giorno fa ho comprato dei cuscinetti a sfera ma sono di una dimensione sbagliata, qualcuno potrebbe gentilmente indicarmi il modello preciso o anche le misure?
grazie

function3d, 2024-01-15:
https://github.com/function3d/petalot/blob/master/BOM.md

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

Closed 2024-01-16.

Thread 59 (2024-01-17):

Dificultad para cortar botellas.

otenmas, 2024-01-17:
Hola, gracias por el proyecto, los vídeos y por ser de ayuda.
Todavía no he descubierto qué estoy haciendo mal pero no puedo cortar las botellas.
Había invertido los rodamientos, donde el rodamiento más alto estaba en el lado donde descansa la garra. Lo arreglé.
Sin embargo, cuando empiezo a tirar de la tira, la botella "sube" y se sale de la "guía", y la tira se estrecha y se rompe. O la botella sigue moviéndose hacia arriba y hacia abajo por la guía y la tira no tiene un tamaño uniforme.

ola, obrigado pelo projeto, pelos videos e por ser solicito.
eu ainda nao descobri o que eu estou fazendo de errado mas eu nao estou conseguindo cortar as garrafas.
Eu tinha invertido os rolamentos, onde o rolamento mais alto ficava do lado onde se apoia a garrava. consertei isto.
Porem quando eu começo a puxar a tira, a garrafa "sobe" e sai do "guia", e a tira se estreita e parte. Ou a garrafa fica subindo e descendo do guia e a tira nao fica com tamanho uniforme.
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

JesConsuegra, 2024-01-20:
Hola Samuel. Yo he montado varios (gracias @function3d  por el diseño) y por lo que veo en tus fotos el corte no es limpio, el afilado de los bordes del rodamiento no debe estar en condiciones. Cuando corta bien va muy suave y queda un corte muy limpio, sin rebabas y suave al tacto. Por otra parte hace falta algún peso para mantener la garrafa en contacto con la base, yo uso una bobina vacía de las de PLA puesta encima del cuello de la garrafa, y con eso va bien. Depende del peso de la bobina puede que haya que poner dos en vez de una. Prueba de "afilar" el rodamiento pasándolo por encima de una hoja de papel de lija sobre una madera plana (con plancha de melamina encima, por ejemplo).

dren-lab, 2024-01-23:
Hola, gracias por responder. Gracias por el consejo de intentar lijar el rodamiento en una superficie plana, porque al lijar con la amoladora, la rectificadora, me da miedo que el rodamiento quede con el borde torcido o inclinado. Adjunto una imagen que es mejor que tratar de explicar con palabras.

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

ola, obrigado por responder. agradeço pela dica de tentar lixar o rolamento em uma superficie plana, pois lixando com o esmeril, a maquina esmerilhadeira, eu tenho receio de que o rolamento fique com a borda torta, ou inclinada. estou anexando uma imagem que é melhor do que tentar explicar com as palavras.

function3d, 2024-01-23:
En realidad es preferible lo primero a lo segundo, nunca lo tercero (orden:
izquierda-derecha, arriba-abajo), me refiero a la imagen que has adjuntado,
es preferible que esté ligeramente no horizontal inclinado hacia el
interior del rodamiento, funciona igual o mejor que completamente
horizontal ya que horizontal perfecto es complicado de conseguir

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

function3d, 2024-01-23:
Tutorial actualizado de como hago el cortador de botellas, incluyo STLs en la descripción compatibles con vuestros actuales rodamientos tornillos y guia https://youtu.be/hEdDhRgakms?si=jsJoxt1nZHrgvoxq

dren-lab, 2024-01-24:
este seria o "bottle-cutter-2.0" ?? preferio fazer só com o 608zz?

function3d, 2024-01-24:
De la versión inicial, desde hace tiempo, hay una versión para 608zz, por
tus fotos no tengo claro cuales son tus rodamientos pero yo llevo haciendo
cutters con el 608zz más de un año, no es que sean preferibles es que son
más fáciles de encontrar y económicos.

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

Closed 2024-02-17.

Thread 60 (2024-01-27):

Dificultad con una de las piezas del nuevo cortador de botellas

JesConsuegra, 2024-01-27:
Hola, en primer lugar felicitarte por el excelente rediseño del cortador, he visto el video y me ha parecido una idea estupenda, por lo que me he lanzado a convertir los mios al nuevo diseño.
La pieza base se ha impreso sin ningún problema, pero la pieza 2 (la ruleta que contiene  el tornillo) al ir a laminarla, Cura 5.6 me dice que la pieza es diminuta y la amplia automáticamente por 100.000 con lo que queda una pieza enorme que llena la base de impresión. Le he quitado un cero y con ampliación de 10.000 aparentemente sale de un tamaño correcto, se imprime correctamente pero al ponerla en la base queda un poco suelta y al meterle el tornillo sólo entra las primeras dos vueltas y con muche esfuerzo.
Podrías por favor revisar a ver si ha habido algñun problema al subir la pieza?
La he cogido de Printables.
Muchas gracias!
Jes.

JesConsuegra, 2024-01-27:
Probado tambien con IdeaMaker 4.3.3 con el mismo resultado.
Saludos,
Jes.

function3d, 2024-01-27:
A mí me dice algo parecido en orca slicer pero el mensaje es que parece
estar en pulgadas y que sí quiero convertirlo a milímetros y al decirle que
si me lo deja bien, tengo que investigarlo

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

function3d, 2024-01-29:
Solucionado, actualizado en printables

JesConsuegra, 2024-01-29:
Mil gracias!!

Closed 2024-01-29.

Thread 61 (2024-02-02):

Firmware flash

AmirMahdaviAM, 2024-02-02:
Hello
Sorry for silly question but, Is it mandatory to flash your firmware bin file or we can compile .ino sketch you provided and write it to wemos?

function3d, 2024-02-02:
You can do whatever you want

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

jadgood, 2024-02-02:
Hola
Cuando intento cambiar el la revoluciones no hace nada la temperatura creo que si.
Hay que cambiar los parámetros de alguna manera para que se queden guardados?

Closed 2024-02-02.

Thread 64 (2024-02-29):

Problemas con el motor

erubenec, 2024-02-29:
Hola,
Lo primero enhorabuena por el proyecto, de todos los que existen en internet me parece el más elegante y sencillo de fabricar, sobretodo por las ganas con las que lo enseñas.

Mi problema es básicamente que el motor no gira nunca, y todavía no he dado con la tecla. Éstas son la lista de cosas que he probado y que a priori descarto del problema:
- Todos los circuitos tienen continuidad (siguiendo el schematic).
- Los voltajes son correctos y tanto el de entrada como el de salida del dc-dc a los demás componentes, al milímetro.
- El controlador del motor está también correctamente configurado (0,51v entre GND y el potenciometro, todo esto siguiendo el último vídeo que subiste donde tú mismo lo haces)
- El wemos, flasheado con la versión 1.2, se enciende correctamente y muestra la interfaz gráfica, parpadea la luz azul y en principio, controla bien todo: calienta el hotend, responde al interruptor de filamento, parpadea la luz azul...
- He intentado medir voltajes tanto en A+ y A- como en B+ y B- y en ningún momento indica valores relevantes (como mucho 0.8v).
- Ningún componente se calienta en exceso.
- Mi motor tiene los dos pines centrales cruzados (A+, B+, A-, B-) a diferencia de otros motores, pero por contra, los dos cables de en medio también están cruzados (A+, A-, B+, B-), por lo que en principio esto no es problema.
- Los componentes son todos los del BOM, los mismos. La máquina es calcada.

Pese a todo esto, el motor nunca gira. Descarto que esté estropeado porque lo he conectado a la impresora 3D sustituyendo uno de los que ya tiene, y gira sin problemas.

Como pista (aunque lo más probable es que no tenga relación) la temperatura que indica la interfaz no corresponde con la temperatura real de la sonda. Estando el hotend totalmente frío, dice que está como a 60 grados. Y si lo pones a calentar empieza a subir, pero retorna valores que fluctúan un montón. Muy sinsentido.

¿Qué me estoy dejando por probar? He pensado en comprar otro controlador del motor ya que apunta a ser el culpable.

Gracias de antemano!

erubenec, 2024-04-16:
Cambié el controlador del motor, parece que vino defectuoso (o el de color verde no le gustaba...) y funciona perfecto.

Closed 2024-04-16.

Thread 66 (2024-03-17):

How to stick ribbons

nico97472-lab, 2024-03-17:
Bonjour,
J'aime beaucoup ton projet je m'en suis inspiré pour avoir le même fonctionnement chez moi
Comment fais-tu pour mettre plusieurs bouteilles dans une bobine
Comment colle-tu les rubans entre eux ?
Merci d'avance
Bonne journée

Good morning,
I really like your project, I was inspired by it to have the same operation at home
How do you put several bottles in a reel ?
How do you glue the ribbons together ?
Thank you in advance
have a nice day

function3d, 2024-04-28:
I have never done that, I splice the filament

Closed 2024-04-28.

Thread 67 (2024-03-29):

Specifications

aamarques, 2024-03-29:
Hy, could you explain about the BOM:

- What's the length of M3 OD 4.2mm Insert Nut for motor mount and electronic box ?
- There's no link for 48mm M6 Rod and I can't found in Ali. The solution is to buy a 50mm and cut ?
- Is the WeMo Mini D1 must be V4 or V3 works ?
- 2 wire cable for limit switch, digital signal. What about the AWG size ?

Thanks

function3d, 2024-04-28:
- 4.2mm
- 48cm, it is a typo, there is not in aliexpress, you will have to get it in a hardware store, about 48cm the measure is not important since it simply has to be longer than the maximum height of your bottles
- Wemos D1 MINI is powered by 5V, internally it operates at 3.3V and has its own voltage regulator
- Is irrelevant, since it is for a digital signal the cable can be any, preferably thin

Closed 2024-04-28.

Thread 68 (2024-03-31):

How to set up a PID

Olsen-perm, 2024-03-31:
Thank you for the project, it is very simple and clear. But I have a problem setting up the PID - the default values give a spread of +-5 degrees, I think that's a lot. How do I start the PID setup? Is there such a possibility?

function3d, 2024-04-28:
PET filament can perfectly manufacture from 120ºC to 250ºC, +-5 degrees is perfectly normal and does not cause any problem at all.

Closed 2024-04-28.

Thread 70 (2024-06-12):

Archivos binarios versus ascii

otenmas, 2024-06-12:
Veo que moviste los archivos STL al sitio web printables.com, menos mal que copié la carpeta github antes. Porque, a pesar de no saber modelar bien 3D, y no entender el tema, noté que algunos archivos antes fueron convertidos a formato binario y ahora están en formato ASCII, lo que resultó en el mismo archivo, por ejemplo "Body_1.stl" Aumenté mucho el tamaño del archivo y presenté un error cuando lo abrí en la segmentación de Cura. Varios archivos ahora tienen un tamaño mucho mayor que antes sin mostrar cambios significativos y presentan un mensaje de error al abrirlos en la segmentación. ¿Se resolverá este problema al exportar en binario?

texto original:
Vejo que moveu os arquivos STL's para o site printables.com, ainda bem que copiei a pasta do github antes. Pois, apesar de nao saber modelar bem 3d, e nao entender sobre o assunto, reparei que alguns arquivos anteriormente estavam convertidos em formato binario e agora eles estao em formato ASCII, o que resultou que o mesmo arquivo, por exemplo o "Body_1.stl" aumentasse em muito o tamanho do arquivo e apresentasse erro quando abro no fatiador Cura. varios arquivos agora estao com tamanho muito maior do que antes sem apresentar mudanças significativas, e apresentam mensagem de erro ao abrir no fatiador. Sera que ao exportar em binario esse proble se resolva?

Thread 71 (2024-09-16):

hot end pull down

tungbuivn, 2024-09-16:
- The ussage of the mosfet is diffrent from transitor, you need to pull down mosfet gate to prevent it random state at the boot, on/off
- because the mosfet may damage by the time, so, it may be short circuit when it done, so im suggest add a opto couple to protect circuit

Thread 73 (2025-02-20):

Motor does not spin, the rest seems ok

i-like-earth, 2025-02-20:
Hi, thanks for the awesome project. Unfortunately I have encountered a problem.

The motor does not spin. It's a Nema 17HS4401S.
When connected to the 3D printer it works fine.
The voltage from converter is exactly 5V and power supply gives 12v.
Stepper driver gives 0.54 V as required and it does work - I've put it in the 3D printer and it run fine.
Wemos D1 is responsive and works via web interface.
Also heater is ok.
I've checked the connections and they are fine.
Also I did everything according to the guide and your videos.

Is there a way to diagnose if Wemos sends right signals to A4988 and A4988 to send right signals to the motor?
Please, I need help, I've run out of ideas.

i-like-earth, 2025-02-28:
Issue resolved.

The main culprit of the problem was poor quality of the main PCB board.
When I've transfered A4988 driver to a breadboard and connected motor directly to the prongs of the driver, motor was moving as it should.

Sadly, after turning the power supply some time after Wemos D1 mini has died. Strange, considering the voltage was 5V exactly.

Again, even after checking the connections and all this work the shoddy work of the PCB manufacturer was the issue all along.

Closed 2025-02-28.

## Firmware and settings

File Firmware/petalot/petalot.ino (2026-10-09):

#define PCB 1501     // Hardware revision: 1405 (DIY) / 1501 / 1502. See pins.hpp
#define VERSION 1604 // Firmware version, independent of the PCB revision

// Compile-time build date extracted from __DATE__ (e.g. "Sep  7 2026")
// Year: '2' and '6' from '2026'
#define BUILD_YEAR_DEC __DATE__[9]
#define BUILD_YEAR_UNI __DATE__[10]

// Day: tens and units (converts a leading space to '0' if day < 10)
#define BUILD_DAY_DEC (__DATE__[4] == ' ' ? '0' : __DATE__[4])
#define BUILD_DAY_UNI __DATE__[5]

// Month: character matching to a two-digit string
#define BUILD_MONTH_DEC (__DATE__[0] == 'J' && __DATE__[1] == 'a' ? '0' : (__DATE__[0] == 'F' ? '0' : (__DATE__[0] == 'M' && __DATE__[2] == 'r' ? '0' : (__DATE__[0] == 'A' && __DATE__[1] == 'p' ? '0' : (__DATE__[0] == 'M' && __DATE__[2] == 'y' ? '0' : (__DATE__[0] == 'J' && __DATE__[2] == 'n' ? '0' : (__DATE__[0] == 'J' && __DATE__[2] == 'l' ? '0' : (__DATE__[0] == 'A' && __DATE__[1] == 'u' ? '0' : (__DATE__[0] == 'S' ? '0' : (__DATE__[0] == 'O' ? '1' : (__DATE__[0] == 'N' ? '1' : (__DATE__[0] == 'D' ? '1' : '0'))))))))))))
#define BUILD_MONTH_UNI (__DATE__[0] == 'J' && __DATE__[1] == 'a' ? '1' : (__DATE__[0] == 'F' ? '2' : (__DATE__[0] == 'M' && __DATE__[2] == 'r' ? '3' : (__DATE__[0] == 'A' && __DATE__[1] == 'p' ? '4' : (__DATE__[0] == 'M' && __DATE__[2] == 'y' ? '5' : (__DATE__[0] == 'J' && __DATE__[2] == 'n' ? '6' : (__DATE__[0] == 'J' && __DATE__[2] == 'l' ? '7' : (__DATE__[0] == 'A' && __DATE__[1] == 'u' ? '8' : (__DATE__[0] == 'S' ? '9' : (__DATE__[0] == 'O' ? '0' : (__DATE__[0] == 'N' ? '1' : (__DATE__[0] == 'D' ? '2' : '0'))))))))))))

// Build-time concatenation into a single String (e.g. "260907")
#define BUILD_VERSION (String("") + BUILD_YEAR_DEC + BUILD_YEAR_UNI + BUILD_MONTH_DEC + BUILD_MONTH_UNI + BUILD_DAY_DEC + BUILD_DAY_UNI)

int major = VERSION / 1000;
int minor = (VERSION % 1000) / 100;
int patch = VERSION % 100;
String version = String("") + major + "." + minor + "." + patch + "." + BUILD_VERSION;

double Ft = 0; // filament total (cm)
double Tt = 0; // time total (s)
double Fs = 0; // filament session (cm)
double Ts = 0; // time session (s)

// Bottle statistics. A bottle is counted as soon as a run crosses the
// threshold, so a reboot mid-run does not lose it.
#define BOTTLE_MIN_CM 300        // 3 m: minimum filament for a run to count as a bottle
int Bt = 0;  // bottles total
int maxFs = 0;   // longest run (cm), for reference
int lastFs = 0;  // last counted bottle length (cm)
bool bottleCounted = false; // current run already added to Bt (counted at threshold)
bool statsDirty = false; // force a stats save after a bottle is counted

// Defined below; declared here so server.hpp can call it.
void saveStats();
void resetStats();

bool OTA_update = false;

unsigned long tempLastStats;
unsigned long tempLastStatsSave;

#include "pins.hpp"
#include "conf.hpp"
#include "wifi.hpp"
#include "stepper.hpp"
#include "hotend.hpp"
#include "display.hpp"
#include "server.hpp"
#include "ota.hpp"

StaticJsonDocument<128> stats;

void setup() {
  Serial.begin(115200);
  // Small delay so the host can attach to the serial port before boot logs
  delay(200);
  initConf();
  initWiFi();
  initOTA();
  initHotend();
  stepper.init();
  InitServer();
  if (UseDisplay) {
    initDisplay();
  }
  tempLastStats = millis();
  tempLastStatsSave = millis();

  File file = LittleFS.open("/stats.json", "r");
  DeserializationError error = deserializeJson(stats, file);
  if (error) {
    // No stats file yet: keep defaults
  } else {
    Ft = stats["Ft"] ? stats["Ft"].as<double>() : 0.0;
    Tt = stats["Tt"] ? stats["Tt"].as<double>() : 0.0;
    Bt = stats["Bt"] ? stats["Bt"].as<int>() : 0;
    maxFs = stats["maxFs"] ? stats["maxFs"].as<int>() : 0;
    lastFs = stats["lastFs"] ? stats["lastFs"].as<int>() : 0;
    bottleCounted = stats["bc"] ? stats["bc"].as<bool>() : false;
  }
  file.close();
}

void loop() {
  ArduinoOTA.handle();
  if (!OTA_update) {
    wifiTask();
    serverTask();
    hotendReadTempTask();
    stepper.task();
    readConfigurationSerial();
    if (UseDisplay) {
      displayTask();
    }
    // Stats follow the motor, not the sensor: with MotorOnTo the motor stays
    // off until the target temperature is reached, and no filament moves (nor
    // time passes for the job) while it waits.
    if ((F || !Fenable) && status == "working" && stepper.motorEnabled &&
        millis() >= tempLastStats + 1000) {
      Fs = Fs + (float)Vo / 60; // cm per second
      Ft = Ft + (float)Vo / 60;
      Tt = Tt + 1;
      Ts = Ts + 1;
      countBottle(); // count as soon as the threshold is crossed
      if (statsDirty || millis() >= tempLastStatsSave + 10000) {
        saveStats();
        tempLastStatsSave = millis();
      }
      tempLastStats = millis();
    }
  }
}

void saveStats() {
  File file = LittleFS.open("/stats.json", "w");
  if (!file) {
    msg = "Failed to create file";
    return;
  }
  stats["Ft"] = Ft;
  stats["Tt"] = Tt;
  stats["Bt"] = Bt;
  stats["maxFs"] = maxFs;
  stats["lastFs"] = lastFs;
  stats["bc"] = bottleCounted;
  if (serializeJson(stats, file) == 0) {
    msg = "Failed to write to file";
  }
  file.close();
  statsDirty = false;
}

void resetStats() {
  Ft = 0; Tt = 0; Fs = 0; Ts = 0;
  Bt = 0; maxFs = 0; lastFs = 0;
  bottleCounted = false;
  statsDirty = true;
  saveStats();
}

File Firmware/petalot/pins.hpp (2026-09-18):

#pragma once

#if defined(ESP8266) && PCB == 1405 // D1 mini

  #define PIN_EN    D1
  #define PIN_STEP  D2
  #define PIN_DIR   D3
  #define PIN_THERMISTER A0
  #define PIN_HEATER D0
  #define PIN_FILAMENT D7
  #define PIN_SCL 99
  #define PIN_SDA 99

#elif defined(ESP8266) && PCB == 1501  // D1 mini, Transitional PCB, Display but no buttons

  #define PIN_EN    D1
  #define PIN_STEP  D2
  #define PIN_DIR   D6
  #define PIN_THERMISTER A0
  #define PIN_HEATER D5
  #define PIN_FILAMENT D7
  #define PIN_SCL D4
  #define PIN_SDA D3

#elif defined(ESP8266) && PCB >= 1502

  #define PIN_EN          D1
  #define PIN_STEP        D2
  #define PIN_DIR         99   // False pin, fixed to LOW via the PCB
  #define PIN_THERMISTER  A0
  #define PIN_HEATER      D0   // 1405 D0
  #define PIN_FILAMENT    D7
  #define PIN_SCL         D4
  #define PIN_SDA         D3   // 1405 PIN_DIR
  #define PIN_BTN1        D6   // 1501 PIN_DIR
  #define PIN_BTN2        D5
  #define PIN_MSI3        D8
  
// TODO
/*#elif defined(ESP32) && PCB == 1502 

  #define LED_BUILTIN     15 
  #define PIN_EN          35
  #define PIN_STEP        33   
  #define PIN_DIR         99   // False pin
  #define PIN_THERMISTER  3
  #define PIN_HEATER      7
  #define PIN_FILAMENT    11
  #define PIN_SCL         16
  #define PIN_SDA         18
  #define PIN_BTN1        9
  #define PIN_BTN2        13
  #define PIN_BTN3        37
  #define PIN_BTN4        39
*/
#else

  #error "Board/version not supported"

#endif

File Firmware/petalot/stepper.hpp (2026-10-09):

#pragma once

#include <Arduino.h>

#include <AccelStepper.h>

// ============================================================================
// MOTOR CONFIGURATION
// ============================================================================
const uint16_t STEPS_PER_REVOLUTION = 200;
const uint8_t MICROSTEPPING = 16;
const uint16_t REAL_STEPS_PER_REV = STEPS_PER_REVOLUTION * MICROSTEPPING; // 3200

// Extruder calibration: 46 stepper revolutions = 29cm of filament extruded
const float STEPPER_REVS_PER_CM = 46.0f / 29.0f;
const float STEPS_PER_CM = REAL_STEPS_PER_REV * STEPPER_REVS_PER_CM;

// ============================================================================
// STEPPER CONTROLLER CLASS
// ============================================================================
class StepperController {
private:
  uint16_t targetRPM = 0;

  AccelStepper accelStepper;

  uint32_t rpmToHz(uint16_t rpm) const {
    return (uint32_t)((float)rpm * REAL_STEPS_PER_REV / 60.0f);
  }

  void applySpeed() {
    uint32_t hz = rpmToHz(targetRPM);
    accelStepper.setSpeed(-(float)hz);
    accelStepper.runSpeed();
  }

public:
  bool motorEnabled = false;

  StepperController()
    : accelStepper(AccelStepper::DRIVER, PIN_STEP, PIN_DIR) {}

  void init() {
    pinMode(PIN_EN, OUTPUT);
#if PCB == 1502
    // Configure microstepping (MSI pins) for the 1.5.2 PCB
    pinMode(PIN_MSI3, OUTPUT);
    digitalWrite(PIN_MSI3, HIGH);
#endif
    digitalWrite(PIN_EN, HIGH); // Disabled at start (active LOW)

    accelStepper.setEnablePin(PIN_EN);
    accelStepper.setPinsInverted(false, false, true); // Enable is active LOW
    accelStepper.setAcceleration(10000);
    accelStepper.setMaxSpeed(rpmToHz(60));
  }

  void setSpeed(float cmPerMin) {
    if (cmPerMin <= 0) return;

    uint16_t newRPM = (uint16_t)(cmPerMin * STEPPER_REVS_PER_CM);
    if (newRPM != targetRPM && newRPM > 0) {
      targetRPM = newRPM;
      applySpeed();
    }
  }

  void enable() {
    if (motorEnabled) return;

    digitalWrite(PIN_EN, LOW);
    motorEnabled = true;

    applySpeed();
    accelStepper.runSpeed();
  }

  void disable() {
    if (!motorEnabled) return;

    accelStepper.stop();

    digitalWrite(PIN_EN, HIGH);
    motorEnabled = false;
  }

  void task() {
    // Temperature safety: if MotorOnTo is set, wait until T >= To - 3°C
    if (MotorOnTo && T < To - 3.0f) {
      disable();
      return;
    }

    // Sync motor state with the global status
    if (status == "working" && !motorEnabled) {
      enable();
    } else if (status == "stopped" && motorEnabled) {
      disable();
      return;
    }

    // Only run if the motor is enabled
    if (!motorEnabled) return;

    // Update speed from Vo (cm/min)
    setSpeed(Vo);

    accelStepper.runSpeed();
  }

  bool isEnabled() const { return motorEnabled; }
  uint16_t getTargetRPM() const { return targetRPM; }
};

StepperController stepper;

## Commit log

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2022-11-04 Update and rename Schematic/How to set 5V output on D3 DC-DC step down.md to before you switching on the electronics.md
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2023-03-23 fix bom link
2024-02-19 Update BOM.md
    corrected the voltage 2v -> 12v
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2026-09-07 fix 8 firmware bugs
    [conf.hpp, hotend.hpp, petalot.ino]
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2026-09-09 control: HOLD floor duty so temperature actually reaches To (tunable via /set)
2026-09-09 control: keep HOLD duty at and just above To, cut only past To+HYS
2026-09-10 web: 1-decimal temperature display; defaults HYS 0.5/HOLD 28; target PCB 1501; update-pcb row restyle
2026-09-10 conf: align HYS/HOLD defaults (0.5/28) in reset and load fallback
    [conf.hpp]
2026-09-10 thermistor: fractional interpolation instead of integer map so T has sub-degree resolution
2026-09-10 web: revert 1-decimal temperature display (back to integer)
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2026-09-10 factory reset keeps hotend tuning (HYS/RAMP/HOLD); confirm text updated in 12 languages
    [conf.hpp]
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2026-09-10 PID regulation as compile-time option (CONTROL_PID) with Kp/Ki/Kd config, anti-windup and filtered derivative
2026-09-10 runtime PID/bang-bang selection (ControlMode), PID default; Kp/Ki/Kd in Advanced tab with tuning help, mode-dependent fields
2026-09-10 web: merge Run tab into General, hide bang-bang UI (PID-only), restyle selects, shorten confirmReset; VERSION 1501
    [petalot.ino]
2026-09-10 web: title-wrapper order (icons first), short disconnected label in all languages; VERSION 1502
    [petalot.ino]
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2026-09-10 docs: map PCB versions to firmware (v1.4.5 DIY / v1.5.1 / v1.5.2 commercial) in Firmware README, with photos and .bin files; update root README electronics
2026-09-10 docs: updating via /update endpoint (works on all versions); Settings update is new in current build
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2026-09-13 web: serialize /tele polling (single-flight + single timer) and abort stale requests after 5s to avoid duplicate chains
2026-09-18 firmware: v1.6.0 (browser-side online update)
    First release of the 1.6 line. Adds the online update that runs in the browser
    (it reads latest.json and downloads the .bin from GitHub, then uploads it to the
    device over the same /updatecheck + /update path as a manual update), keeps the
    manual ESPAsyncHTTPUpdateServer updater untouched, splits PCB from VERSION,
    sets explicit DNS for static IP, and shows firmware + PCB version in the UI
    footer.
2026-09-18 builds: versioned bin names (petalot.<hw>-v<fw>.bin)
    Rename the published firmware to include both the hardware and the firmware
    version (e.g. petalot.1.5.2-v1.6.0.bin), keep only the latest build per active
    PCB, and preserve the legacy petalot.v1.2.bin and petalot.1.4.4.bin.
    - release.sh: build petalot.<hw>-v<fw>.bin and delete previous versioned bins
    - gen_latest_json.py: emit the versioned file names in latest.json
    - .gitignore: keep legacy bins and allow petalot.*-v*.bin
    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
2026-09-19 tools: webui_preview.py to preview the web UI without flashing
    Extracts web_ui.h, serves it in the browser and answers /get, /tele, /set,
    /reset, /updatecheck and /update either with synthetic data (mock) or by
    forwarding to a real device (--device URL). web_ui.h is re-read on every page
    load, so edit and press F5. Adds Firmware/tools/README.md.
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2026-09-19 firmware: bottle statistics + preview tooling
    - Count bottles from the processed filament length (threshold configurable),
    persisted in /stats.json; count as soon as the threshold is crossed so a
    reboot mid-run does not lose it.
    - Statistics tab: Current/Total (filament, time, bottles), Longest/Last and a
    note that length is an estimate. Reset statistics in Advanced with a
    confirmation modal; reuse the modal for Save and Factory Reset.
    - Header shows Current and Total. 12-language i18n; drop the litre size groups.
    - webui_preview.py: bottles fields in the mock and /resetstats.
    [hotend.hpp, petalot.ino]
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2026-09-20 web: UI layout polish
    - Group fields with dashed separators; move Temperature Offset to General.
    - Move Factory Reset next to Reset statistics in Advanced; keep a single Apply
    button shown only on General and Network tabs.
    - Drop the redundant Online update heading (buttons are self-explanatory).
2026-09-22 i18n: add Spanish parts lists (parts-list-*.es.csv)
    [parts-list-cutter.es.csv, parts-list-electronics.es.csv, parts-list-petalot.es.csv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]
2026-09-22 fix: correct descriptions in parts-list-petalot (EN/ES)
    [parts-list-petalot.csv, parts-list-petalot.es.csv]
2026-09-23 links: update AliExpress links in parts lists (EN/ES)
    [parts-list-cutter.csv, parts-list-cutter.es.csv, parts-list-electronics.csv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]
2026-09-23 links: power supply and 4.8mm terminals (EN/ES)
    [parts-list-electronics.csv, parts-list-electronics.es.csv]
2026-09-23 feat: add variation column to parts lists (EN/ES)
    [parts-list-cutter.csv, parts-list-cutter.es.csv, parts-list-electronics.csv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]
2026-09-23 chore: clean variation values (drop colors/lot units)
    [parts-list-cutter.csv, parts-list-cutter.es.csv, parts-list-electronics.csv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]
2026-09-23 feat: split/merge items and clean variations (EN/ES)
    [parts-list-electronics.csv, parts-list-electronics.es.csv, parts-list-petalot.csv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]
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2026-09-23 feat: PCB product link in component description (EN/ES)
    [parts-list-electronics.csv, parts-list-electronics.es.csv]
2026-09-23 fix: PCB row has no AliExpress link (links live in Component)
    [parts-list-electronics.csv, parts-list-electronics.es.csv]
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2026-09-23 fix: M8x105mm -> M8x110mm in component (EN/ES)
    [parts-list-petalot.csv, parts-list-petalot.es.csv]
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2026-09-23 feat: wooden base row in parts list (no link); markdown updated
    [parts-list-petalot.csv, parts-list-petalot.es.csv]
2026-09-23 feat: wooden base image embedded in component (lightbox), no image_url
    [parts-list-petalot.csv, parts-list-petalot.es.csv]
2026-09-24 Update wooden base entry in parts list
    [parts-list-petalot.csv]
2026-09-24 refactor: prices/lots/status in CSV; generator reads them; BOM shows price+total
    [parts-list-cutter.csv, parts-list-cutter.es.csv, parts-list-electronics.csv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]
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2026-09-24 data: Nema 17 motor new link + price 11.19 (EN/ES)
    [parts-list-electronics.csv, parts-list-electronics.es.csv]
2026-09-24 data: fix Nema 17 link (_c39SiyRr)
    [parts-list-electronics.csv, parts-list-electronics.es.csv]
2026-09-24 chore: reorder electronics list (EN/ES); revert base image_url in ES
    [parts-list-electronics.csv, parts-list-electronics.es.csv, parts-list-petalot.es.csv]
2026-09-24 data: remove 4.8mm insulating sheath from electronics (EN/ES)
    [parts-list-electronics.csv, parts-list-electronics.es.csv]
2026-09-24 data: new image for 4.8mm female terminal (EN/ES)
    [parts-list-electronics.csv, parts-list-electronics.es.csv]
2026-09-24 data(es): mirror EN strip-sensor wording in electronics CSV
    [parts-list-electronics.csv, parts-list-electronics.es.csv]
2026-09-24 data(es): mirror EN strip-sensor note on micro limit switch
    [parts-list-electronics.csv, parts-list-electronics.es.csv]
2026-09-24 fix(csv): quote comma in micro limit switch description (EN/ES)
    [parts-list-electronics.csv, parts-list-electronics.es.csv]
2026-09-24 data: micro limit switch variant Roller Lever Arm, price 2.24 (EN/ES)
    [parts-list-electronics.csv, parts-list-electronics.es.csv]
2026-09-24 data: micro limit switch new link, variant Pulley, price 1.89, lot 10 (EN/ES)
    [parts-list-electronics.csv, parts-list-electronics.es.csv]
2026-09-24 data: drop obsolete MS-1A-14.5-P from micro limit switch description (EN/ES)
    [parts-list-electronics.csv, parts-list-electronics.es.csv]
2026-09-30 web: fix factory reset confirmation copy (12 languages)
    - State clearly that the target temperature and temperature offset survive a
    factory reset; drop the misleading heating tuning mention (PID is forced and
    its controls are hidden).
2026-10-09 firmware: v1.6.4
    - thermistor: cold ambient is no longer reported as a thermistor fault.
    Report T_AMBIENT_MIN (25 C) below the usable range and only fault on an
    open/short ADC reading, so the machine starts in a cold room.
    - stats: only accumulate filament and run time while the motor is enabled,
    so MotorOnTo does not count time/filament while waiting for temperature.
    - stepper: start the motor at To - 3 C instead of To - 6 C.
    [display.hpp, hotend.hpp, petalot.ino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]
2026-10-09 web: reload UI whenever the connection returns
    The page already reloaded when the device came back after a firmware
    update (via waitForReboot). Detect the offline-to-online transition in
    the /tele poll and reload for any reconnect (settings reboot, factory
    reset, Wi-Fi blip, update). Skip the first sample after a page load to
    avoid a reload loop.
2026-10-18 firmware: configurable device name for header and Wi-Fi AP
    Add a DeviceName setting: shown in the web UI header and appended to
    PETALOT- to build the Wi-Fi AP SSID. Falls back to the MAC tail when
    empty. The value is sanitized to SSID-safe characters and capped at 24,
    and saving it reboots the device so the AP renames.
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2026-10-19 firmware: show the real AP name in the UI and fix the recovery note
    Factor the access-point SSID out of AP() into apSsidName() and expose it
    in /get as apSsid, so the web UI shows the actual name (PETALOT- plus the
    device name, or the MAC tail when no name is set) instead of a literal.
    The i18n strings use an {ap} placeholder filled on load and on language
    change.
    The AP password help now says the only recovery is clearing the
    configuration from the serial console, which is what actually works when
    the AP is the only link to the device. Added a 'reset' serial command to
    wipe the configuration and reboot, so that recovery is a single command.
2026-10-19 web: scanned Wi-Fi as a clickable list, and mock /scan in the preview
    The SSID field used a datalist, which browsers filter by the text already
    typed, so the scanned networks did not show when an SSID was configured.
    Replace it with a list of chips: all found networks, sorted by signal,
    tap one to fill the field. Show a distinct message when none are found.
    webui_preview.py now mocks /scan so the picker can be tested without
    flashing.
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2026-10-19 app: v1.10, periodic refresh replaces the search button, show version
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2026-10-20 data: recheck AliExpress prices (Oct 2026), new links for M3 nut and DC-DC converter
    All 48 purchasable rows re-measured on es.aliexpress.com (EUR, logged out),
    selecting the variant listed in the `variation` column.
    - 96 price cells updated (44 up, 4 down, median +2.3%)
    - M3 nut: new listing, price 2.01, lot 50
    - Mini DC-DC: new listing, price 3.39, lot 5
    - M4x35, M3x20, M8 lock nut and cable sleeve corrected by hand
    - shared parts aligned across the machine and cutter lists
    BOM total: 159.05 -> 158.78 EUR
2026-10-20 data: re-measure prices with stable reads, fix stale prices after variant click
    The previous run read the price right after clicking the variant, so some rows
    kept the price of the previously selected option (M4x35 showed the M4x30 price).
    Prices are now read only after the value repeats three times in a row.
    - 7 rows corrected: 10K, 2K, hotend, 5mm/2mm heat shrink, M8 washer, 80W iron
    - 41 of 48 rows matched the previous revision, confirming the rest
    - shared rows stay aligned between the machine and cutter lists
    BOM total: 158.78 -> 157.99 EUR
2026-10-20 data: add power cable (EU/US/UK/AU plug) to the PETALOT machine list
    Option depends on the buyer's country: 3.49 (US) to 4.59 (AU). The row keeps the
    EU option (4.49) so the total stays correct, and the description tells the buyer
    to pick their own plug and shows the range.
    Image uploaded to the site media library (power_cable.webp) instead of hotlinking
    the AliExpress CDN.
    BOM total: 157.99 -> 162.48 EUR
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2026-10-24 web+wifi: keep password focus, retry home Wi-Fi from fallback AP
    Password toggle: mousedown no longer steals focus, and the click gives
    it back to its field (with the cursor kept) only if the field had it.
    The fallback AP is no longer a dead end: with a home SSID configured,
    wifiTask retries joining it every 5 minutes while nobody is using the
    AP, non-blocking so heating continues. After 15 s without association
    it returns to the AP. Retries pause during OTA.
2026-10-24 wifi: patient boot association before falling back to AP
    A weak radio often needs several attempts, but the boot gave up after
    10 s and latched the fallback AP. Re-issue WiFi.begin() every 15 s
    (3 s after a stack-reported failure) and only fall back to the AP after
    3 minutes. Short drops once associated are left to the SDK
    auto-reconnect, which recovers in seconds without leaving STA.
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2026-10-26 web: note that the OLED needs a full power cycle
    The SSD1306 shares the MCU reset line, so a software reboot does not
    bring the screen up. The display toggle already saves without
    rebooting; the help text now tells the user a full off/on is required.
2026-10-26 display: status header, dual temperatures and blinking run dot
    New 128x64 layout: PETALOT vX.Y header with a dot that blinks left of
    RUNNING while working (off + STOPPED when idle), TEMP ACTUAL vs TARGET
    columns with degree glyph, and a VEL line with the run timer below.
    Drops the old speed animation bitmap, which no longer fits the layout.
2026-10-26 display: inverted state pill, separators, small target
    State badge as an inverted pill (contrasts with normal and inverted
    screens), blinking dot inside it while working. Divider lines below
    the header and the temperatures. Target temperature in small size,
    centred with the big actual value.
2026-10-26 display: custom layout with pills, remove Invert display option
    Keep the drawUI restyle (header pill, TEMP/TARGET columns, inverted
    target pill, PACE pill, colon timer). Drop the Invert display setting
    and force normal mode at init so a stale inverted state cannot survive
    a soft reboot. Degree glyph stays 247 as seen on hardware.
2026-10-26 display: BTN3 menu with selectable zones on RX
    BTN3 (RX/GPIO3, button to GND) cycles the selected LCD zone:
    RUNNING/STOPPED, target temp, speed. The selected zone shows normal
    polarity instead of its inverted pill. BTN1/BTN2 act as +/- on the
    selected zone (long press steps 20), or start/stop on the state zone.
    RX gets its own pull-up since it floats with USB unplugged; release
    all buttons while flashing.
2026-10-26 display: selected zone gets the pill, either button toggles run
    The inverted pill now marks the zone being edited instead of every
    zone. On the RUNNING/STOPPED zone both BTN1 and BTN2 toggle
    start/stop according to the current state.
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
